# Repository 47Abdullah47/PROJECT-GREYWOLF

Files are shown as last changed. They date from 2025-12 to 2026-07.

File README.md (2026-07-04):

<h1 align="center">﷽</h1>
<h1 align="center">
<font size="6"><b>🛦 X-26 GREYWOLF PT-1</b></font>
</h1><br>

<h4 align="center">
  <b>The First High-Performance Experimental 12S EDF Prototype of the YF-26 GREYWOLF Program</b>
</h4>
<p align="center">
  <a href="#technical-specifications">Technical Specifications</a> •
  <a href="#visual-looks">Visual Looks</a> •
  <a href="#airframe-materials-list">Materials</a> •
  <a href="#electronics--propulsion-system">Electronics Strategy</a> •
  <a href="#system-wiring-diagram">Wiring Diagram</a> •
  <a href="#success-criteria--flight-goals">Flight Goals</a> •
  <a href="#assembly-guide">Assembly</a> •
  <a href="#credits">Credits</a> •
  <a href="#license">License</a>
</p>
<br>

> **Project Status:** Prototype 1 (PT-1) Engineering, Aerodynamic Simulation & CAD Phase Complete  
> **CAD Platform:** Autodesk Fusion 360  
> **Development Pipeline:** [Hack Club Stasis Dashboard](https://stasis.hackclub.com/dashboard/projects/cmnfqlx3300nv01qimu2rgsk3)  
> **Design Time Investment:** 50+ Hours of High-Fidelity Surface Modeling  
> **Source CAD File:** 💾 [Download Massive Fusion 360 (.f3d) Assembly via Google Drive](https://github.com/47Abdullah47/X-26-GREYWOLF-PT-1/blob/Main-Project-PT-1/SOURCE%20FILE.md)

---

## Technical Specifications

The **X-26 GREYWOLF PT-1** is a high-speed, scratch-built experimental scale RC jet aircraft. It is engineered around an advanced integrated propulsion duct system and a multi-axis high-lift control surface layout to study level transonic airflow behaviors, intake fluid dynamics, and low-altitude flight stability.

* **Total Length of Aircraft:** 1.3 - 1.5 meters
* **Total Height of Aircraft (without landing Gear):** 0.3m (~30cm)
* **Fuselage Hull Height:** 0.1m (~11cm) *(Optimized to wrap tightly around the internal engine bay)*
* **Wingspan:** ~1.0 meter
* **Wing Area:** ~0.1 m²
* **Total Control Channels:** 6 Channels (2x Flaps, 2x Ailerons, 2x Stabilators)
* **Aerodynamic Design & Fluid Optimization:** Validated via rigorous computational fluid dynamics (CFD) steady-state solver testing run at a 20 m/s airspeed vector, establishing a baseline cruise lift coefficient ($C_L$) of 0.0141 and an ultra-low geometric shape drag coefficient ($C_D$) of 0.0018.
* **Special Intake Engineering:** Features a custom-modeled internal S-Duct intake routing system designed to stabilize incoming air turbulence and manage static pressure gradients under high mass flows.
* **Performance Profile:** Estimated empty airframe weight ranges from 2.0 to 3.0 kg. Powered by a high-output 12S electric ducted fan producing between 4.0 - 5.0 kg of static thrust, yielding a >1:1 thrust-to-weight ratio for a flight envelope targeting 100 - 110 mph.
* **Short-Runway (STOL) Takeoff Speeds:**
  * *Unladen / Light Test Rig (3.5 kg):* 21.3 m/s - 23.0 m/s (~76 km/h)
  * *Maximum Operational Testing Payload (4.5 kg):* 24.6 m/s - 26.1 m/s (~94 km/h)
* **Control Surface Mixing:** Implements symmetrical **Flaperon** mixing, deflecting both flaps and main ailerons together at takeoff. This transforms **41.5% of the total wing area ($372.68\text{ cm}^2$)** into an active camber-shifting high-lift surface, rocketing the maximum takeoff lift coefficient ($C_{L_{\text{max}}}$) to approximately 0.165.

*Note: The structural frames, nose cone mechanics, and intake paths are modeled as completely independent components within the source assembly to allow for modular fabrication and fast battery bay accessibility.*

---

## Visual Looks

<h3 align="center"><b>CAD Model Overview</b></h3>
<p align="center">
  CAD Side Perspective
  CAD Front-Side Perspective
  CAD Front Perspective

  <a href="https://youtu.be/b9qI-MGt7ME"><b>A demonstration of the actuation of Control Surfaces</b></a>

</p>

<h3 align="center"><b>High-Fidelity Rendered Visuals</b></h3>
<p align="center">
  Render 1
  Render 2
  Render 3
  Render 4
</p>

> **Design Note on Airframe Influence:** > The X-26 Greywolf airframe merges generation-defining design aspects. It utilizes high-efficiency forward intakes inspired by the F-22 Raptor, twin vertical stabilizing surfaces and an exhaust layout optimized similarly to the F-35 Lightning II, and an internal structural distribution derived from the F-16 Fighting Falcon. 

---

## Airframe Materials List

The structural framework utilizes a lightweight, high-strength composite prototyping approach to handle structural stress thresholds while maximizing the power-to-weight ratio:

1. **Depron Foam / High-Speed LW-PLA:** Used for the aerodynamic outer skin contours, wing surfacing, and lightweight internal fuselage formers.
2. **Carbon Fiber Spars & Rods (3mm):** Integrated directly into high-stress structural joints, serving as the main wing load spars, tail pivot shafts, and longitudinal fuselage stiffeners.
3. **Aircraft-Grade Plywood:** Selected for high-vibration structural hardpoints, specifically the main 12S EDF engine mount and landing gear mounting plates.

---

## Electronics & Propulsion Strategy

The PT-1's avionics bay is engineered to safely sustain high continuous current loads. Comprehensive component sourcing, unit prices, and specific funding breakdowns are tracked in the dedicated [Bill of Materials Guide](BOM.md).

### Power Architecture Summary:
1. **High-Voltage Power Loop:** Two independent 6S LiPo battery packs (5200mAh - 5900mAh) are linked in **series** using a heavy-duty **QS-8 Anti-Spark Series Harness** to deliver a unified 12S nominal voltage supply (44.4V nominal / 50.4V peak) directly to the ESC.
2. **Propulsion Drive Loop:** High-gauge phase leads feed directly from the Hobbywing 100A V2 ESC to the brushless motor inside the 80mm fan shroud.
3. **Low-Voltage Signal Loop:** Signal power to the 10-channel FlySky receiver steps down cleanly via the ESC's integrated Battery Eliminator Circuit (BEC) lines.
4. **Control Surface Actuation:** Symmetrical servos are linked across the receiver layout using heavy-duty Y-harness extensions to maintain precise dual-aileron, dual-flap, and stabilator mechanical sync.

---

## System Wiring Diagram

The PT-1 utilizes a clean point-to-point wiring schematic optimized for minimal line resistance and spatial balance within the narrow fuselage ribbing. 

<p align="center">
  Point to Point Wiring Schematic
  Internal Fuselage Electronics Layout
</p>

---

## Success Criteria & Flight Goals

To rigorously evaluate the airframe engineering and telemetry code, the testing program focuses on three definitive goals:
1. **Aerodynamic Validation:** Confirm stable, level cruise tracking at a 20 m/s airspeed vector to ground-truth our baseline steady-state CFD dataset.
2. **STOL Performance:** Verify short-runway rotation and lift-off performance using the 41.5% trailing-edge flaperon configuration under incremental payload loads.

---

## Assembly Guide
The proper assembling procedure of the aircraft is as follows:-
<h3><b>THE SPINE</b></h3>
<p>The airduct of the plane has two major and very important roles in the aircraft, it serves as <b>THE SPINE</b> of the plane and the **The duct that** asissts the airflow.
It being <b>The Spine</b>  of the airplane, it will be the one hosting the airframe ribs.
</p>
 

<h3><b>Air-Frame Ribs Placement</b></h3>
<p>  The cuted out airframed ribs are slided onto the air duct, which is the spine of the aircraft. 
</p>


 <h3><b> First Skin Placement</b></h3>
 After sliding on the Airframe ribs onto the Airduct..The lower fuselage skin is mounted onto the airframe ribs.


<h3><b>Mounting Side panels</b></h3>
After mounting lower skin panel of the fuselage..the side skin panels are mounted onto the Airframe.


<h3><b>Adding support</b></h3>
3mm Carbon fibre rods are slided into the premade holes in airframes..the goal is to provide the airframe with a good tensile and torsion strength.
Also one of the rear support ribs are slided onto the carbin fibre rod for attatching to the main spine and be a part of the barrier against crushing G-force..Also the remaining side panels of the fuselage are mounted onto the rear support ribs.


<h3><b>Mounting Inner Skin Panels</b></h3>
Rear Inner skin panels are also mounted onto the rear support ribs.


<h3><b>Construction of the Stabs(stabilators)</b></h3>
The stab's construction is simple yet requires carefullness regarding the building process...The root aerofoil is mounted on the outer edges of the stab.


After mounting the root aerofoil on the root edge of lower skin panel of the stab...
the upper skin panel is mounted onto the root aerofoil and the corresponding outer edges of the lower skin panel....


After sucessfully mounting skin panels and the root aerfoil to eachother...the pivot rod is slided into the premade hole in the root aero foil.... 
The stabilators are done being built.


<h3><b>Mounting The Remaining Skin Panels</b></h3>
The remaing rear lower skin panels of the fuselage are also mounted onto the rear support ribs of the Fuselage..with the side skin panels supporting it.


After completing mounting the rear side of lower skin panels..The rear skin panels of the upper skin are also mounted onto the rear support ribs....


After mounting first rear skin panel of the upper skin...the second pair of skin panels are mounted onto the Airframe ribs...these two skin panels are directly sitting above the main propulsion unit of the UAV..


The side long skin panels are also mounted onto the Airframe ribs..these skin panels cover up the most of the Fuselage's upper skin....


The front upper skin panels of the Fuselage are mounted onto the front Airframe Ribs of the Airframe with the remaining upper side panels of the Airframe....the Cavity behind these panels is the space of the removeable panels that allow accessing the inner components of the Aircraft without needing to rip-apart the skin of the Aircraft.
 

A brief 3d view for the Construction described so far.
<video src="https://github.com/user-attachments/assets/6bf46d65-2bc3-4322-bec0-19ca2d736067" autoplay loop muted width="100%"></video>

<h3><b>Mounting Engine Nozzle</b></h3>
The Engine nozzle is consisted of 5 panels..the first three panels are mounted onto the correspeonding edges of the Inner side panels and Upper skin panels....


The fourth skin panel of the Engine nozzle is mounted onto the corresponding edges of the lower skin panel and onto the corresponding side edges of the second and thord side panels of the engnine side panels.


the last panel is the exhuast panel of the engine bay section, this can be replaced by a servo operated variable engine nozzle too, which is not the part of current development.


<h3><b>Installing the Nose ribs, nose panels, And completing the Fuselage</b></h3>
The Nose is installed by folowing a complex assembling procedure, the Battery block itself serves as a support, The two nose ribs are slided onto the carbon fibre rods, In this way the base of the nose is installed onto the Fuselage.


The lower nose skin panels are installed onto the assembled Structure of the Nose


After mounting the lower panels the side Skin panels are mounted onto the so far assembled nose strucutre.


After that The next Nose Rib is installed by three support brigdes,


After adding the next rib, the corresponding side Skin panels are mounted.


After mounting Side skin panels, the corresponding upper Skin panel is mounted 


after that, another Rib is added to the structure, and corresponding remaining side skin panels are mounted on, 


After that the last remaining upper skin panel is mounted.


THE DIVERGERS:-
The divergers are mounted on the tip of the lower intake Skin panel, Its purpose is to separate the low speed skin air from the high speed air,


After All of this process the Construction of the Fuselage is done.


<h3><b>Assembling the V-tails</b></h3>
The Ribs of the tails are mounted onto the one side of the Skins of the tail, 


After joining the Ribs with one skin, The other skin is mounted onto the ribs and the other skin,


Just like this the second tail is constructed, After joining skins and the ribs of the tail, the lower base root panel is mounted, sealing the whole structure,


After that carbon fibre support rods are slided into pre-built holes in the root panel,


This support rib is situated perpendicular to the actuator support of the STABS, its purpose is to lockin the Carbon fibre support Rods of the V-tails.


The Tails are slided into the Fuselage, Like This, (this is the inner view removing the outer skin panel from the vie)


And with that The V-tails are fused into the Fuselage.


<h3><b>Assembling the Wings</b></h3>
The front Ribs of the wing are fitted into the slots of the front spar, 



after fitting the ribs into the front spar, the main spar is slided onto the sleves of the ribs


After fitting the Main spar, the sleves of the Rear Ribs are slided into the main spar


the edge support ribs are then slided into gltye rear sleves of the rear ribs,




after that the Rear spar is fitted into the joint intersections made into the ribs and the spar.


After This step the Main Root aerofoil bulkhead is slided into the spar sleves to complete the structure of the removeable wings.


The two 5mm Carbon fibre rods are then slided into the holes and then locked using the collars inside the wings, so that the wings can be slides on and removed for easy transportation. 


The upper skin of 2mm depron is mounted onto the complex wing structure.



After mounting the upper depron skin, the lower depron skin is mounted to complete tge aerodynamic shape of the wing, also for servo fittings, there are pre cutout parts on the lower depron skin



And after that the sides of the wing, the "WING TIPS" are mounted on,


After mounting the wing tips, the
control surfaces "Flaps and Ailerons" are mounted onto the hinges that are fitted into the hinge support ribs, And the removeable wings are Completed


Now the 6mm wings' support bulkhead is installed into the airframe ribs and with the support rib similar to the root rib of the wing, enabling those two 5mm carbon fibre rods to be slided into the airframe,


This is how the Wing is installed, the carbon fibre rods are tightened up with the help of collars,


<h3><b>The Actuation Mechansim of Flaps and Ailerons</b></h3>
This is where the servos for Flaps and Ailerons go into the eing, and the actuation mechanism is shown perfectly below👇 


<h3><b>The Actuation Mechansim of the Stabilators</b></h3>
This is how the pushrods for the actuation of Stabilators reside,
a collar is installed onto the 3mm carbon fibre rod, that is connected to the stabilator, and the pushrod is used to rotate the collar which in turn, turns the rod, actuationg the stabilator

This is where the servo resides into the rear support ribs.

<h3><b>The Residence of The ESC</b></h3>
The esc is placed in the lower storage bay in the Airframe, that is near the lower skin panel and below the peak before dice of the Airduct.


<h3><b>Placement of the EDF</b></h3>
The EDF is placed onto the mounting brackets installed between the Airframe ribs, And is directly placed into the Airduct with the mouth directky attached to the exit of the Airduct to prevent any Airfeed Loss.
(The Air duct is hidden for a bteer view on the placement of the EDF)


<H3><B>Placement of the Reciever</B></H3>
The reciever/flight controller is placed in the upper storage bay that is direclty below the mid upper skin panel, The reason is to prevent any electrical noise from interfering with the reciver/FC, and for extending the antennas into carbon fibre free sections to prevent signal screening.


<h3>Placement of the batteries </h3>
The two 6s lipo packs are slided into the battery block that is also serving as the lower spine of the nose section, The block has cutouts on the upper sides to allow the wires to flow into the rear section of the UAV, and tye charging wires to be accessed easily.




<h4><b>THE END</b></h4>
And the Assembling process comes to an end. The product should,.must look like this



---

## Credits

* **My Father:** A seasoned professional in his aviation field who taught me the foundational mechanics of aircraft design, and inspired me to build this dream.
* **My Brother:** The catalyst who challenged me to test my limits, stepped up my design thinking, and introduced me to the open-source hardware community.
* **Hack Club Blueprint & Stasis Teams:** For establishing a development pipeline that empowers teenagers to scale up their hardware engineering skills and bring complex concepts to life.

---

## License

This project is open-source and licensed under the terms of the MIT License.

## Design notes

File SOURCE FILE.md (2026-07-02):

# 💾 X-26 GREYWOLF PT-1 Source CAD Files

Welcome to the source files for the PT-1 prototype! These models were designed from the ground up in **Autodesk Fusion 360** (50+ hours of surface modeling). 

The project's files are split into two distinct versions:

### 📐 1. Master Manufacturing Model (Zero Thickness)
This is the foundational surface model. It contains the raw, unthickened aerodynamic skins, S-Duct pathways, and master sketches.
Provided for confirmation of the project evolution, and for confirmation that the work is self done, not borrowed from anyone else.
* 📥 [Download Zero Thickness File (.f3d)](https://drive.google.com/file/d/1hmdceTrVBTGaHWRErnbGDeAFzKetScAU/view?usp=sharing)

### 🛡️ 2. Welded Section Assembly (Thickened Panels)
Is the more optimized and better assembly containing Editor file and also has the Electronics and actuation mechanisms for the control surfaces.
* 📥 [Download Thickened Section File (.f3d)](https://drive.google.com/file/d/12EBaJtmXtbBg36lhwlMjGNUEtxX0ZkJ4/view?usp=sharing)

---

### ⚠️ A Quick Note for Stasis Reviewers
The the reason for providing G drive links is that, They are quite massive crossing over to 104mb-150mbs, 
so plz dont mind clicking an extra link in the process.

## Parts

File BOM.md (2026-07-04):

# 📊 Bill of Materials (BOM) — X-26 GREYWOLF PT-1

This document tracks the complete physical budget, part breakdown, and sourcing roadmap for the primary prototyping phase of the X-26 GREYWOLF jet aircraft. All items listed below are requested to be covered by a mix of direct upfront purchasing and the local reimbursement method.

### 💳 Complete Component & Budget Breakdown

| Component / Material Name | Qty | Unit Price | Sourcing Route & Funding Method | Sourcing Link / Details |
| :--- | :---: | :---: | :--- | :--- |
| **80mm 12S Electric Ducted Fan (EDF) Unit** | 1 | $86.87 | **Direct Grant Purchase** (Upfront) | [AliExpress Sourcing Link](https://www.aliexpress.com/item/1005005825766168.html) |
| **6S 22.2V 5200mAh 40C LiPo Batteries** | 2 | PKR 19,000 | **Local Purchase** (Apply for Reimbursement) | [Electrobes Lithium-Polymer Sourcing](https://electrobes.com/product/5200mah-22-2v-6s-40c-lipo-lithium-polymer-rechargeable-battery-pack-for-rc-drone/) |
| **Hobbywing Skywalker 100A V2 High-Voltage ESC** | 1 | PKR 10,800 | **Local Purchase** (Apply for Reimbursement) | [SmartHobby](https://www.smarthobby.pk/product-page/hobby-wing-skywalker-100a-v2-esc) |
| **Depron Foam Sheets (5mm Thickness, 60x60cm)** | 6 | PKR 750 | **Local Purchase** (Apply for Reimbursement) | [Electrobes](https://electrobes.com/product/depron-sheet-kt-foam-board-for-diy-aeroplane-model-glider-5mm-thickness/) |
| **TowerPro MG-90 180° Micro Servos** | 6 | PKR 2,700 | **Local Purchase** (Apply for Reimbursement) | [Electrobes](https://electrobes.com/product/towerpro-sg-90-servo-motor-180-degree-rotation/) |
| **3mm Carbon Fibre Rods** | 8 | PKR 880| **Local Purchase** (Apply for Reimbursement) | [Electrobes](https://electrobes.com/product/3mm-high-quality-carbon-fiber-rod-for-rc-plane-diy-tool-high-strength-light-weight-solid-bar/) |
| **5mm Carbon Fibre Rods with 3mm hole** |4| PKR 1,080 | **local Purchase** (Apply for Reimbursement) |[Electrobes](https://electrobes.com/product/5mm-carbon-fiber-rod-with-3mm-hole-diameter-for-rc-plane-diy-tool-high-strength-light-weight/)]|

---

### 🛠️ Sourcing Strategy Notes for Reviewers

1. **Direct Sourcing ($86.87 USD):** The specialized 80mm 12S EDF propulsion core is requested via upfront direct grant ordering as it requires international procurement to match specific aerodynamic design parameters.
2. **Reimbursement Sourcing (Local Parts):** To eliminate international shipping delays and accelerate the build cycle, all supporting electronics (ESC, Servos, structural carbon spars), the primary 12S battery configuration, and the 5mm Depron airframe skin panels will be procured locally from regional suppliers.
3. **Total Project Financial Footprint:** ~$146.33 USD + Local Materials (PKR 55,100 total for local components). 100% of the hardware stack is tied directly to operational flight capability.

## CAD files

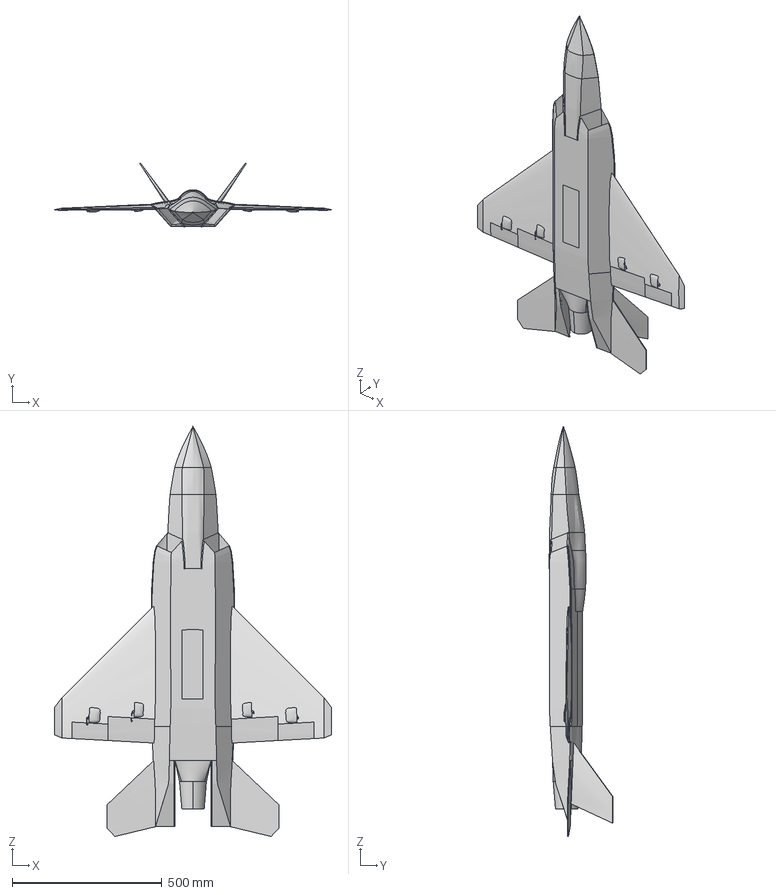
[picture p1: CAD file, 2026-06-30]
CAD FILES/3mf Type/Assem full body.3mf
925.9 x 214.7 x 1370.3 mm

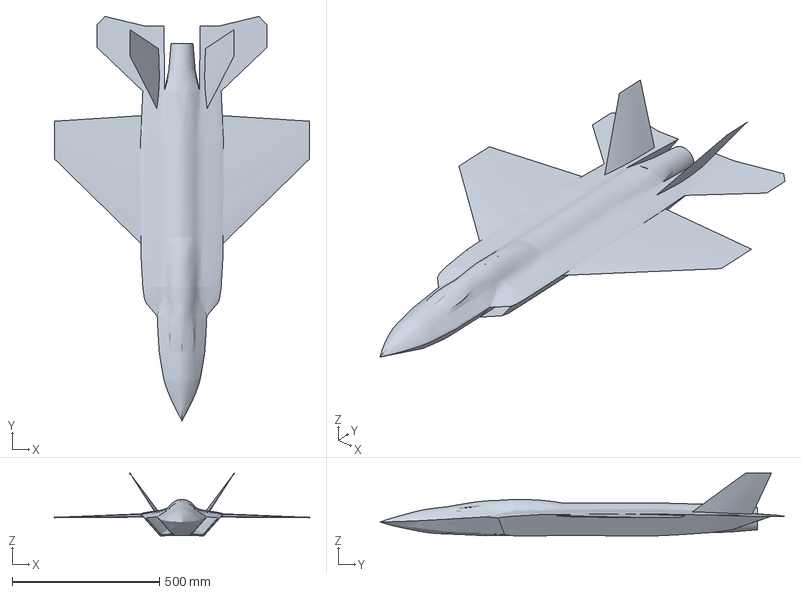
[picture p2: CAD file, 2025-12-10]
3d files/Prototype 1.3mf
864.6 x 1370.3 x 212.1 mm

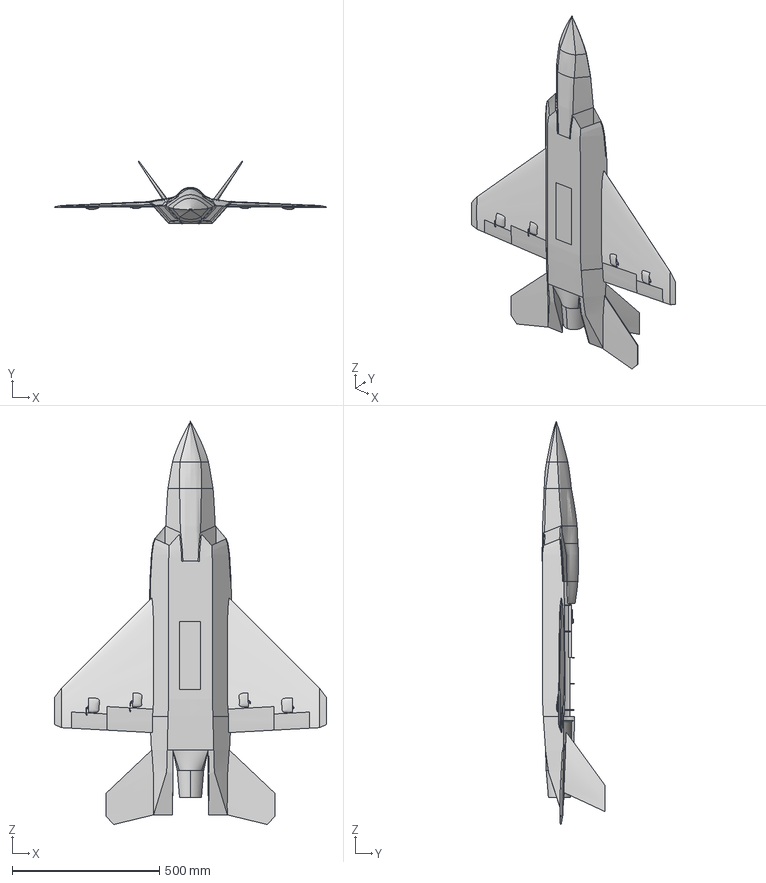
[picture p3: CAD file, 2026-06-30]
CAD FILES/3mf Type/Assem cut away.3mf
925.9 x 214.7 x 1370.3 mm

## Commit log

2026-03-30 Update cost for 80mm Edf in Bill(BOM).csv
    Updated the cost of 80mm Edf and corrected the URL.
    [Bill(BOM).csv]
2026-04-22 Update README with printing cost considerations
    Added note about printing costs and material alternatives.
2026-04-23 Create SOURCE FILE.F3D
    [SOURCE FILE.F3D]
2026-04-23 Update README with BOM and wiring diagram
    Added section for BOM and wiring diagram instructions.
2026-04-23 Update total cost in Bill(BOM).csv
    [Bill(BOM).csv]
2026-04-23 Modify Bill(BOM) with additional purchase links
    Updated item details and added links for purchases.
    [Bill(BOM).csv]
2026-04-27 Revise build recommendations and remove 3D printing details
    Updated the recommendations for building the project, emphasizing the prototyping status and potential errors. Removed detailed 3D printing material suggestions and table for parts.
2026-05-28 Update SOURCE FILE.F3D
    [SOURCE FILE.F3D]
2026-06-13 Update item quantities and costs in Bill(BOM).csv
    [Bill(BOM).csv]
2026-07-04 Update README.md
    Updated the Assembly description
